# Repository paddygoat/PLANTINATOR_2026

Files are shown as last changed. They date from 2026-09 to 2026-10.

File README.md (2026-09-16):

# PLANTINATOR 2026

PLANTINATOR 2026 explores a practical way to develop machinery with complex moving geometry: describe the mechanism in Python, refine it with an LLM such as GPT Astra, and inspect its movement in a dedicated Qt5 simulation application. When the mechanism is ready for further engineering, construct the corresponding model in FreeCAD and add the surrounding structure. This combines repeatable geometry generation, rapid visual feedback, and conventional CAD detailing in one development workflow.

The real world objective is to build a transplanting machine simplified as below:
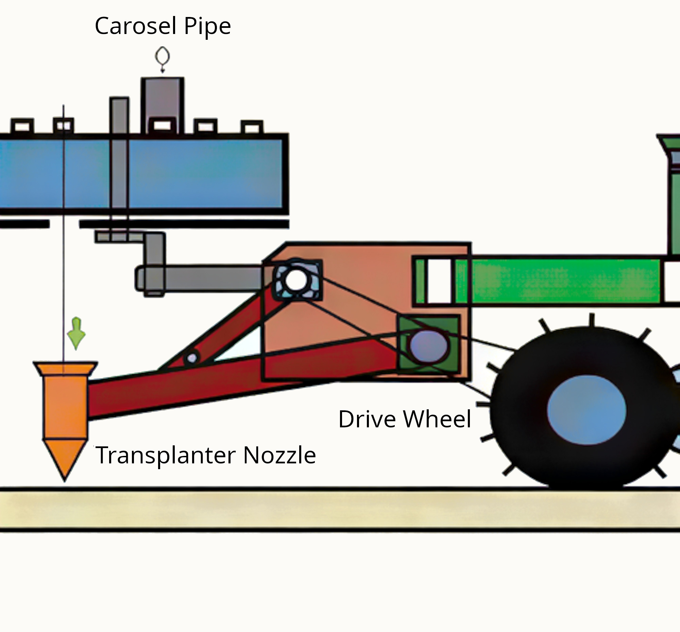
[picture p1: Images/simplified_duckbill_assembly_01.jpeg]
Simplified duckbill assembly


Progress so far:
Watch the PLANTINATOR video on YouTube (https://youtu.be/es3N6XBZsP0)

[Watch the video on YouTube](https://youtu.be/es3N6XBZsP0).

The repository contains a lugged wheel and chain mechanism, including paired wheels, a shared shaft, sprockets, and individual chain components. Its dimensions and motion relationships are expressed in code, making the assembly suitable for systematic changes rather than repeated manual reconstruction.

## Why describe moving geometry in Python?

Building an assembly manually in FreeCAD involves more than drawing its individual parts. Components must have consistent dimensions, occupy the correct positions, and maintain their intended relationships as the mechanism moves. Repeated features, such as wheel lugs and chain links, multiply the positioning work. A change to wheel spacing or sprocket geometry can affect several other parts of the design.

A Python macro captures these relationships explicitly. Dimensions become named parameters; repeated shapes come from functions and loops; placements follow mathematical rules. Instead of editing every affected component separately, the designer changes the relevant inputs and regenerates the assembly. FreeCAD also supports parametric modelling through its interface, but code makes large sets of repeated operations especially straightforward to reproduce and review.

In this project, parameters describe features such as disc diameter, lug count, chain pitch, and wheel spacing. The current sprocket tooth counts are 28, 15, and 21, despite older comments mentioning 13 teeth. Reading the executable parameters therefore matters more than relying on historical labels. The wheel and first sprocket share a defined rotational relationship, preserving their intended shaft synchronisation during animation.

## Working with an LLM

An LLM can help translate mechanical intentions into changes to the Python model. A request might be: “Increase the distance between the wheels while keeping the shaft ends flush with the outer bosses.” The useful result is a change to the relevant dimensions and relationships, which the designer can inspect, run, and revise.

This reduces the effort of writing repetitive modelling operations, tracing dependencies, and adjusting placement calculations. It also makes experimentation accessible through ordinary language. A designer can describe the desired arrangement, ask for an explanation of the geometry, and request a specific alteration without manually repeating every CAD operation.

The strongest workflow uses small, explicit requests. State the dimensions, coordinate directions, fixed relationships, and expected motion. Review the resulting code, then inspect the model. Keep successful revisions in version control so that alternatives can be compared or reversed. The LLM assists with implementation; the designer decides whether the mechanism meets its engineering requirements.

## Faster visual checks with Qt5

The dedicated application in [Simulator_app](Simulator_app/) shortens the feedback loop between changing a model and seeing it move. It uses PySide2 for Qt5, Pivy/Coin with OpenGL for display, and FreeCAD’s Part geometry kernel to construct the solids. It does not require the full FreeCAD desktop interface for each inspection.

That distinction is useful during frequent revisions. Opening FreeCAD, loading or rerunning a macro, waiting for document construction, and arranging the view introduces repeated interaction. The dedicated viewer concentrates on the mechanism and its controls, allowing human attention to stay on the geometry and motion. The practical speed advantage comes from this focused workflow and reuse of display geometry; no benchmark is claimed here.

The viewer displays tessellated CAD surfaces, including holes, chamfers, bosses, sprocket teeth, and chain details. During playback, it updates component transformations rather than rebuilding every solid for every frame. Controls include play/pause, signed speed, stepping by one chain pitch, and a position slider. Standard views, orbit, pan, zoom, lug inspection, and chain close-ups help examine details from useful angles.

Use **Load dimensions** to read supported numeric constants from a Python file and rebuild the view. This feature does not execute arbitrary selected macros: geometry comes from the bundled `source_model.py`. New geometry logic must therefore be incorporated into that source and the application restarted or rebuilt. Keep the CAD macro and simulator source consistent when developing changes.

Check the default source path before launching: the repository stores its CAD macro inside `CAD/`, while the simulator currently expects it at repository root.

## Continue the design in FreeCAD

The workflow retains a route into a native FreeCAD document. Open [FreeCAD_Simulator.FCMacro](Simulator_app/FreeCAD_Simulator.FCMacro) in FreeCAD and execute it, keeping its sibling files together. It runs the bundled geometry source and creates actual document objects. Save the resulting document as an `.FCStd` working file for subsequent editing.

This handoff is more precise than treating the standalone viewer as a general CAD exporter. The current application does not provide a universal working-file import/export pipeline. If dimensions were loaded from another file in the viewer, transfer those accepted values into the bundled source before generating the FreeCAD document. Verify that both environments show the same arrangement.

Once inside FreeCAD, static items can be added such as the supporting frame, bearing mounts, brackets, guards, or mounting plates. Use the mechanism’s shaft positions and movement envelope to guide their placement. Keep these additions organised separately and save a separate working document before rerunning generation code, which creates a fresh mechanism document. Generated solids do not automatically provide a complete sketch-based feature history.

## A practical development cycle

Start with the Python geometry, ask the LLM for a clearly bounded change, and inspect the revised mechanism in Qt5. Check several positions across a complete cycle, including close approaches and reversals. Once the arrangement is satisfactory, generate the FreeCAD document and develop the supporting structure around it.

The simulator uses a continuous pitch-circle approximation, rather than a rigid-link contact solver. It does not calculate loads, traction, tension, or collisions. Visual agreement supports geometric development, while fabrication still requires dimensional, clearance, and mechanical checks. Used together, Python, LLM assistance, Qt5 visualisation, and FreeCAD make complex mechanisms easier to iterate and understand.

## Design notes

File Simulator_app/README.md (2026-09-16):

# WEEDINATOR detailed wheel and chain simulator — v3.2

## Start the updated app

Close the older running app, then run:

```bash
python3 app.py
```

The window title reads **WEEDINATOR · detailed CAD viewer · Qt5 · v3.2**. This is now the default application. It uses installed **PySide2 (Qt5)**, **Pivy/Coin with OpenGL**, and **FreeCAD's Part geometry kernel**. These dependencies are present on the machine where the app was built. Use the system Python compatible with FreeCAD; installing a generic package named FreeCAD with pip is not a substitute. On a system with a different FreeCAD library location, set `FREECAD_LIB` to the directory containing `FreeCAD.so`. A desktop display and working OpenGL context are required.

## Front disc rendering update (v3.2)

CAD checks confirm that the disc is 590 mm in diameter, has a 6 mm axial thickness, two rearward chamfered steps and an intact 30 mm bore. The renderer now meshes each CAD face separately and supplies explicit analytic surface normals, keeping flat plate faces separate from rounded edges and bore walls. It also explicitly requests a 24-bit depth buffer, enables depth testing and writing, and tightens the camera clipping range around the assembly to improve separation of thin surfaces. These changes address rendering artifacts without changing dimensions.

Regression tests verify flat front/back normals, mesh bounds and volume, as well as the original lug details. The reported visual distortion cannot be directly confirmed in the build session because a desktop display is unavailable.

## OpenGL startup fix (v3.1)

The Linux launcher now selects Qt's X11/GLX desktop OpenGL backend to match the installed Coin library. QApplication is created before Coin initialisation. The viewer requests a compatibility context without requiring multisampling, makes its context current before drawing, and checks both Qt and native GLX before entering Coin's renderer. If context creation fails, the app pauses and shows an error instead of calling Coin without a context. It does not disable Coin's context assertion.

An X11/XWayland display is required. The launcher checks display connectivity before constructing QApplication. Settings are scoped to the app process; system graphics configuration is unchanged.

For a driver issue, try Mesa software rendering:

```bash
python3 app.py --software
```

This retains the detailed CAD solids and uses Mesa software OpenGL instead of hardware acceleration. It still requires a working graphical display.

## Why details were missing

The older Tkinter viewer manually drew simplified polygons. Its lug blades were plain rectangles; it never generated the hole cuts, chamfers or welded flange solids. Qt5 by itself cannot restore omitted geometry.

The new viewer builds the original bundled CAD geometry and tessellates its actual surfaces at a 0.15 mm tolerance for OpenGL display. This includes the **10 mm lug chamfers, 12 mm through-holes, 6 mm flanges, stepped wheel face, rim, boss, sprocket tooth cuts and chain plates/pins/rollers**. OpenGL depth testing handles visibility. The screen shows tessellated solids rather than the older schematic.

The lug holes run along the tangential direction through the blades, so the startup front view sees them edge-on. Click **Lug detail** to pause and focus on the first blade from a slightly oblique side angle. Chamfers and the through-hole can then be inspected. A hole can still be hidden by other geometry when viewing from a different direction.

The disc has two rearward 12 mm steps. Their 45-degree chamfers start at radii 200 mm and 105 mm, ending at 188 mm and 93 mm respectively. The central land is 24 mm behind the outer land, with the hub seated on it. The rear profile follows the stepped front at a 6 mm axial offset.

## Controls

The right-side **Simulation & 3D camera** panel includes:

- Play/Pause, step one pitch, reset motion, signed chain speed, and chain-position slider.
- Front, Back, Top, Right and Isometric views.
- Orbit horizontally/vertically, roll, pan and zoom.
- **Restore startup view**: restores the front orientation and full-assembly framing.
- **Lug detail**: pauses, shows the wheel and focuses on a blade.
- **Chain close-up**: frames the sprockets and chain.
- Wheel visibility and loading another file's numeric dimensions.

Drag to orbit. Shift-drag or right-drag to pan. Scroll to zoom. Camera changes do not alter mechanism dimensions or shaft synchronisation. Startup remains the previous front view; animation starts paused.

Startup defaults to `../lugged_wheel_with_sprockets_chain.py`, and the file picker starts at that file. The bundled lug geometry includes three 10 mm chamfers, including the inner corner furthest from the disc.

**Load dimensions** reads direct numeric constants from a macro with the same parameter names; missing values use bundled defaults. It does not execute the selected file. Only the trusted bundled `source_model.py` supplies executable geometry code. This is a simulator for this assembly family, not a general macro interpreter.

## Other entry points

The older lightweight Tkinter schematic remains available explicitly:

```bash
python3 app.py --schematic
```

It is simplified and does not display the new CAD details.

For a native FreeCAD document, open **FreeCAD_Simulator.FCMacro** inside FreeCAD and execute it. Keep all sibling files together. This version has its own Qt dock and retains the original axonometric startup view. It requires `FreeCADGui` and creates actual document objects; the standalone Qt5 app uses the geometry kernel without the FreeCAD desktop UI.

## Source fidelity and limits

The source has `T1 = 28` despite older comments saying 13T. The app uses **28T / 15T / 21T**, with 58 pitches at 12.7 mm: a 736.6 mm loop. The solved second centre is approximately (136.120482, 0) mm and the third is (0, −140) mm.

The wheel rotates 1:1 with the first sprocket, plus `WHEEL_PHASE_OFFSET`, at Z = −50 mm. Geometry is retained from the bundled source; the original user file is untouched.

Motion retains the original continuous pitch-circle approximation. Angular speed is chain speed divided by pitch radius, which differs slightly from ideal integer tooth ratios. Equal arc-distance roller spacing produces chords shorter than the fixed chain pitch on arcs, so slight link/roller alignment discrepancies can remain. This is not a rigid-link/contact solver and does not calculate loads, traction, tension or collisions.

## Verification

```bash
python3 -m unittest discover -s . -v
```

Fifteen tests cover OpenGL backend selection and the no-context render guard, as well as the original path/rotation behaviour, dimension input, schematic camera math, CAD lug validity, actual hole/chamfer cutouts, tessellated detail vertices and shaft synchronisation. CAD tests require FreeCAD's Python libraries.

The Qt5 window, CAD scene construction, playback operations and camera controls have also passed a headless smoke test with `QT_QPA_PLATFORM=offscreen`. A missing-context smoke test also confirms that rendering is skipped and an error is shown without a Coin abort. These checks do **not** validate the final OpenGL image: a working desktop display was unavailable in the build session.

## Plain boss and shaft

The plain front boss is OD 50 / ID 30 x 30 mm, seated on the recessed centre. A local-X diameter-12 hole passes through its midpoint with a simplified M12 x 70 hex bolt and nut (threads omitted). The OD 30 x 954 mm shared shaft extends rearward with its front (+Z) end flush with the boss front face and remains solid and undrilled. The bolt intentionally intersects the shaft pending a later shaft-hole change.

## Rear rim closure

The Ø550 mm rim extends 74 mm rearward from the main Ø590 mm disc. A Ø550 x 6 mm closing disc meets its far end and extends another 6 mm rearward (local Z −80 to −74 mm; total rearward depth 80 mm). Its Ø30 mm centre bore accommodates the shaft.

A second plain boss (OD 40 / ID 30 x 7 mm) is seated on the outside of the rear closing disc, extending rearward from local Z −80 to −87 mm.

## Second wheel

A complete second wheel, including both discs, rim, 12 lugs, both bosses and locking fasteners, is rotated 180 degrees about Y. The centres of the 80 mm rim + rear-disc envelopes are 850 mm apart along negative Z. Its reference plane is 930 mm behind the first. Both wheels rotate together with one solid OD 30 x 954 mm shaft, flush with the two outward-facing front boss faces. Shaft holes remain uncut.

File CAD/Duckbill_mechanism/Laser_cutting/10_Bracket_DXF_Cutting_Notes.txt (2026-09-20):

Units: millimetres. Scale 1:1. All geometry on CUT layer. No kerf compensation.
Horizontal bracket: cut 2 from 6 mm steel; 4 x diameter 10 holes at 15 mm pitch.
Upright bracket: cut 4 from 3 mm steel; 3 x diameter 6 holes, middle pivot offset outward 20 mm.
Rounded profiles and tube-fitting cutout are included.
[
  {
    "file": "10_Horizontal_Tube_Bracket_84x24_6mm_4Holes.dxf",
    "thickness_mm": 6,
    "quantity": 2,
    "width_mm": 84.0,
    "height_mm": 24.0,
    "closed_contours": 6,
    "entities": {
      "CIRCLE": 4,
      "LINE": 5,
      "ARC": 6
    }
  },
  {
    "file": "10_Upright_Bracket_OffsetPivot_3mm.dxf",
    "thickness_mm": 3,
    "quantity": 4,
    "width_mm": 42.0,
    "height_mm": 60.0,
    "closed_contours": 4,
    "entities": {
      "CIRCLE": 3,
      "LINE": 7,
      "ARC": 3
    }
  }
]

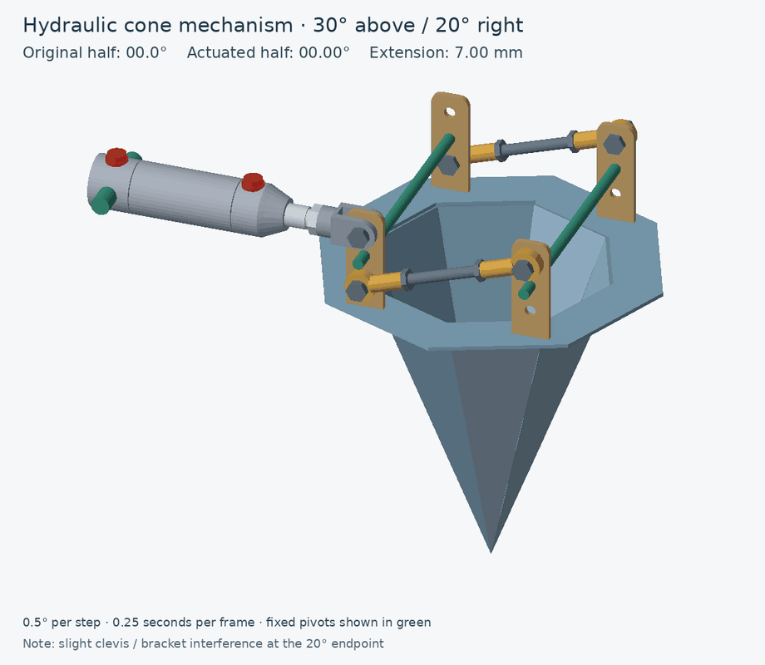
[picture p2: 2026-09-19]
Images/Hydraulic_Cone_3D_30Above_20Right_025sec.gif

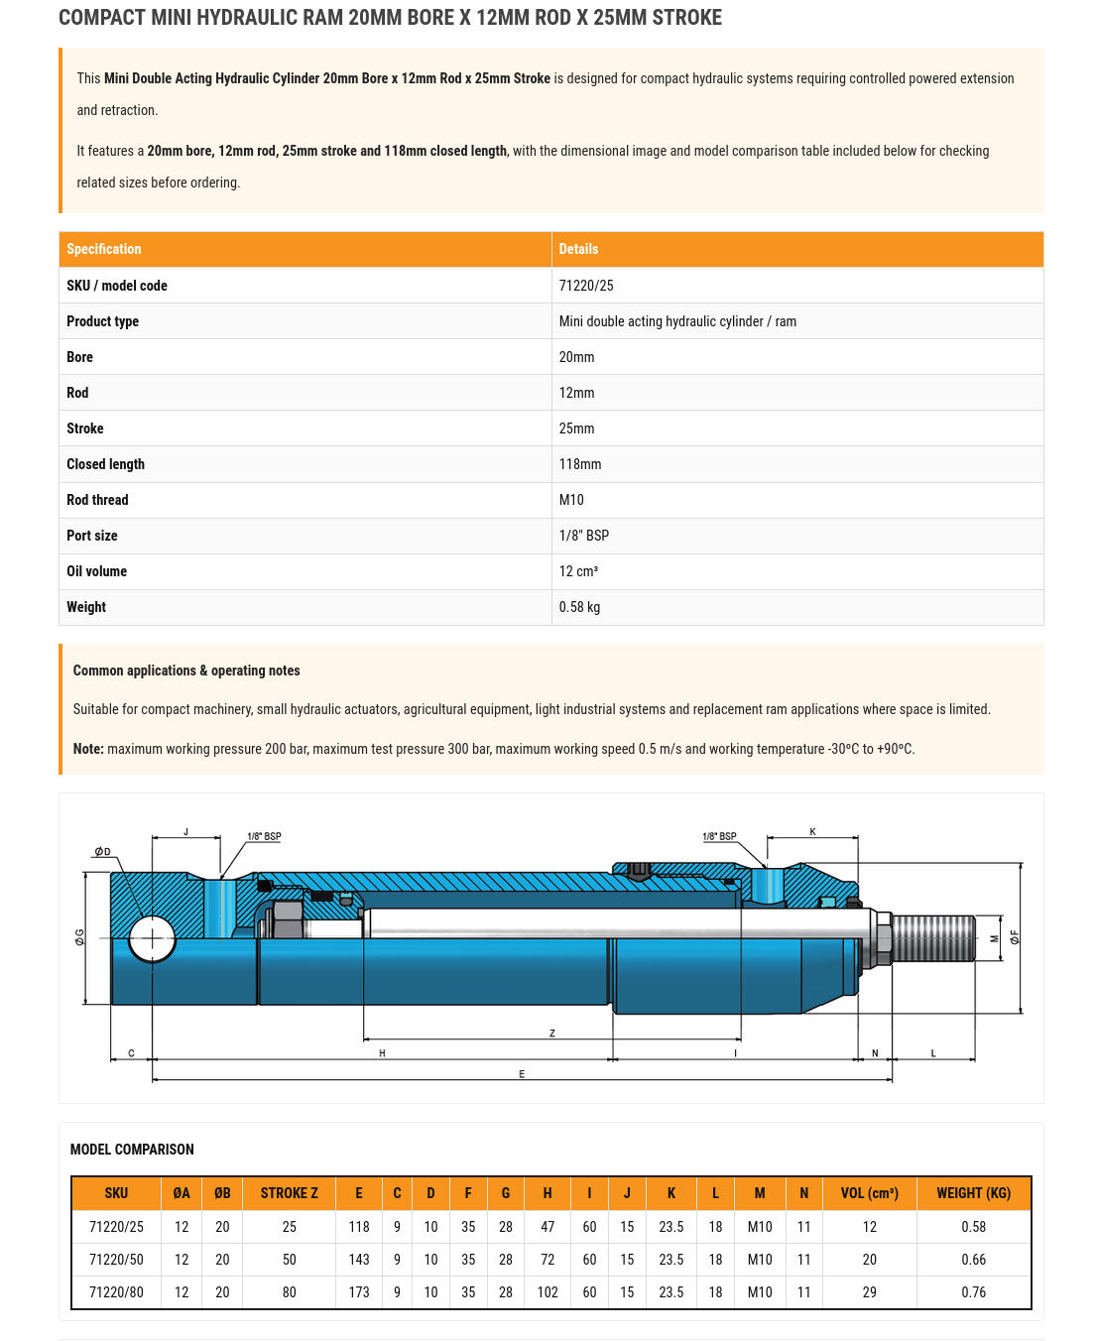
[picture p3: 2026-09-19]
Images/hydraulic_cylinder/Screenshot 2026-09-19 at 22-36-25 Mini Hydraulic Cylinder 20mm Bore x 25mm Stroke Flowfit.png

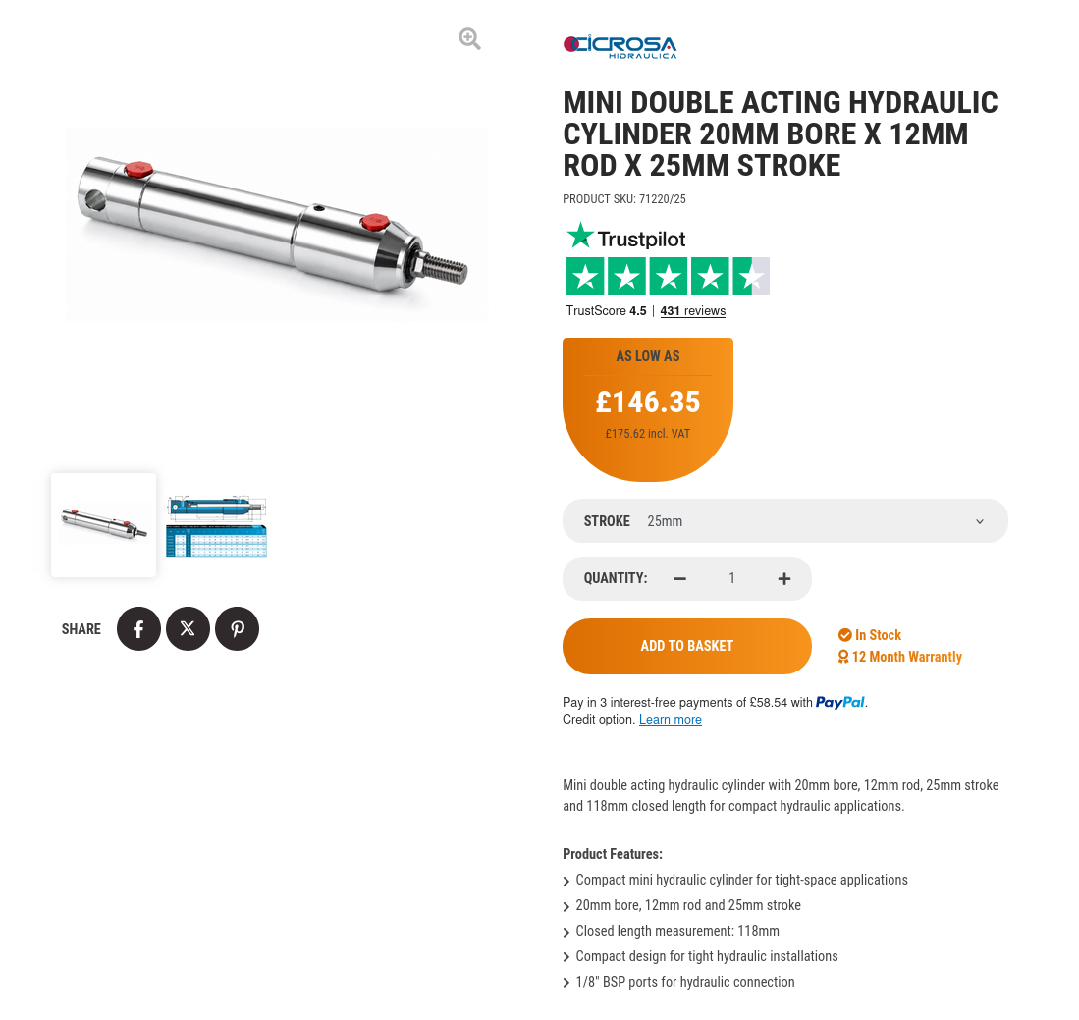
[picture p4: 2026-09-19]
Images/hydraulic_cylinder/Screenshot 2026-09-19 at 22-35-51 Mini Hydraulic Cylinder 20mm Bore x 25mm Stroke Flowfit.png

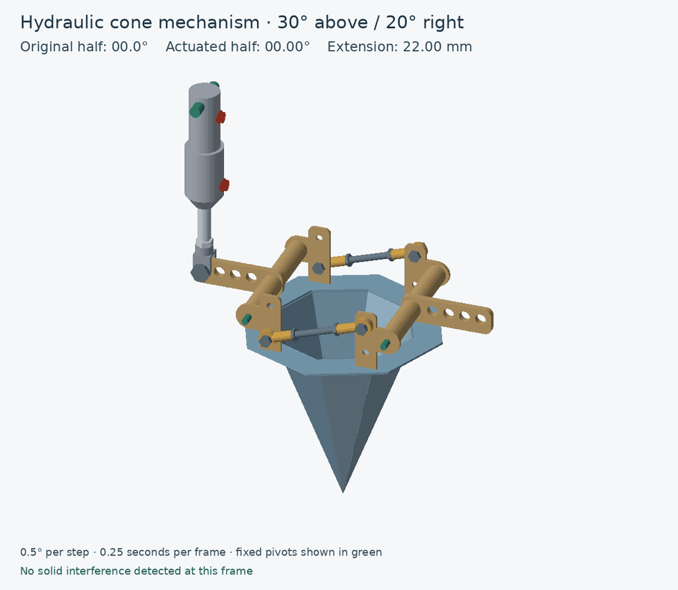
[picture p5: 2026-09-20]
CAD/Duckbill_mechanism/Images/10_Demi_Cone_Adjustable_Brackets_0_20_0.gif

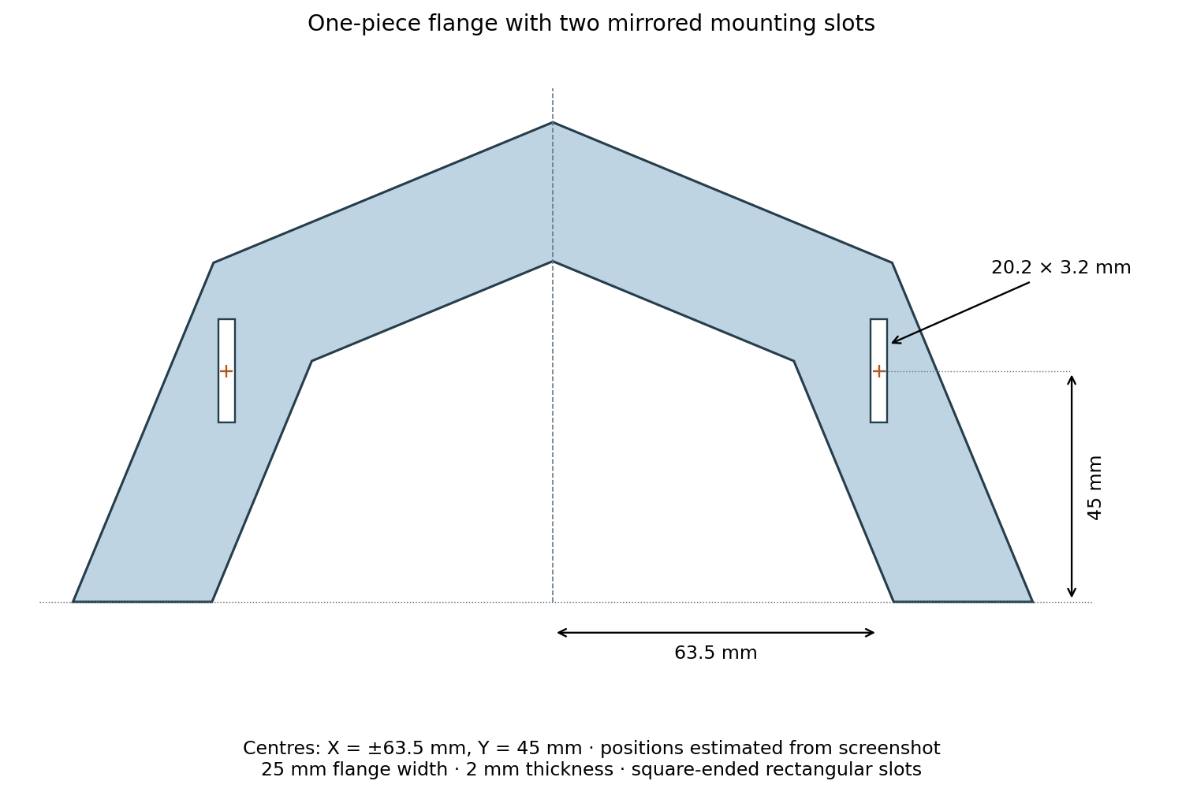
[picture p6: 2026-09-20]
CAD/Duckbill_mechanism/Laser_cutting/Flange_2Slots_Drawing.png

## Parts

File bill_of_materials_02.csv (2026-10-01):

Part Description | Num Reqd | Currency | Cost ex VAT each | Total cost incl VAT | Supplier 1 | Supplier 2 | Item Web Address
PrimaryChainDrive Orange 82L | 2 |  | n/a | n/a
Wheel shaft 64T to sprocket 10T_02 chain yellow 138L | 2 |  | n/a | n/a
Upper wheel 32T chain drive Green 60L | 2 |  | n/a | n/a
sprocket_16T_01 Orange 16T | 4 | £ | 7.85 | 9.42 | Simply Bearings |  | https://www.simplybearings.co.uk/products/pw-s-08b-16
sprocket 15T tensioners Orange Yellow 15T | 6 | £ | 7.63 | 9.16 | Simply Bearings |  | https://www.simplybearings.co.uk/products/pw-s-08b-15
wheel_shaft_sprocket_64T Yellow 64T 08B | 2 | £ | 35.11 | 84.264 | Simply Bearings |  | https://www.simplybearings.co.uk/products/pw-s-08b-64
sprocket_10T_02 Yellow 10T 08B | 2 | £ | 6.21 | 14.904 | Simply Bearings |  | https://www.simplybearings.co.uk/products/pw-s-08b-10
wheel shaft sprocket 32T 01 Green 32T 08B | 4 | £ | 14.95 | 71.76 | Simply Bearings |  | https://www.simplybearings.co.uk/products/pw-s-08b-32
upper wheel tensioner 12T 01 Green 12 T 08B | 2 | £ | 6.37 | 15.288 | Simply Bearings |  | https://www.simplybearings.co.uk/products/pw-s-08b-12
SKU: 08B-1-5MTR-MB Branded 08B-1 BS Simplex Roller Chain 1/2 inch Pitch 5 Meters, 394 L | 2 | £ | 27.2 | 65.28 | Simply Bearings |  | https://www.simplybearings.co.uk/products/08b-1-5mtr-mb
SRB45/2-20 15/30 Tooth Metric En8 Steel Bevel Gear Set 2:1 Ratio 4.5 MOD 20deg Pressure Angle | 1 | £ | 232.94 | 279.53 | Simply Bearings |  | https://www.simplybearings.co.uk/products/srb45-2-20-15-30-tran
SRB35/2 16/32 Tooth Metric En8 Steel Bevel Gear Set 2:1 Ratio 3.5 MOD 20deg Pressure Angle | 1 | £ | 146.59 | 175.91 | Simply Bearings |  | https://www.simplybearings.co.uk/products/srb35-2-16-32-tran
SRB30/2 16/32 Tooth Metric En8 Steel Bevel Gear Set 2:1 Ratio 3.0 MOD 20deg Pressure Angle | 1 | £ | 126.51 | 151.81 | Simply Bearings |  | https://www.simplybearings.co.uk/products/srb30-2-16-32-tran
Wilwood 0.750 inch Integral Brake/Clutch Master Cylinder – RD3621 260-1304 | 2 | £ | 42.43 |  | Rally Design |  | https://www.ebay.co.uk/itm/232571162100
Wilwood Pull Type Clutch Slave Master Cylinder – 260-1333 | 2 | £ | 86.99 |  | Rally Design |  | https://www.ebay.co.uk/itm/331572254785

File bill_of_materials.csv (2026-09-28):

Part DescriptionNum ReqdCurrencyCost ex VAT eachTotal cost incl VATSupplier 1Supplier 2Item Web Address
PrimaryChainDrive | Orange | 82L2n/an/a
Wheel shaft 64T to sprocket 10T_02 chain | yellow | 138L2n/an/a
Upper wheel 32T chain drive | Green | 60L2n/an/a
sprocket_16T_01 | Orange | 16T4
sprocket 15T tensioners | Orange | Yellow | 15T6
wheel_shaft_sprocket_64T | Yellow | 64T 08B2£35.1184.264Simply Bearingshttps://www.simplybearings.co.uk/products/pw-s-08b-64
sprocket_10T_02 | Yellow | 10T 08B2£6.2114.904Simply Bearingshttps://www.simplybearings.co.uk/products/pw-s-08b-10
wheel shaft sprocket 32T 01 | Green | 32T 08B4£14.9571.76Simply Bearingshttps://www.simplybearings.co.uk/products/pw-s-08b-32
upper wheel tensioner 12T 01 | Green | 12 T 08B2£6.3715.288Simply Bearingshttps://www.simplybearings.co.uk/products/pw-s-08b-12
SKU: 08B-1-5MTR-MB Branded 08B-1 BS Simplex Roller Chain 1/2 inch Pitch 5 Meters, 394 L2£27.265.28Simply Bearingshttps://www.simplybearings.co.uk/products/08b-1-5mtr-mb
Sub Total£251.496
Part DescriptionNum ReqdCurrencyCost ex VAT eachTotal cost incl VATSupplier 1Supplier 2Item Web Address

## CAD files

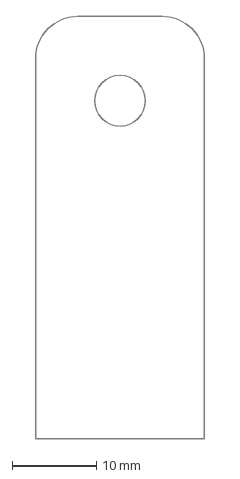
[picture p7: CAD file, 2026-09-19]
CAD/Duckbill_mechanism/Bracket_20x50x3_with_6mm_hole.dxf
20.0 x 50.0 mm

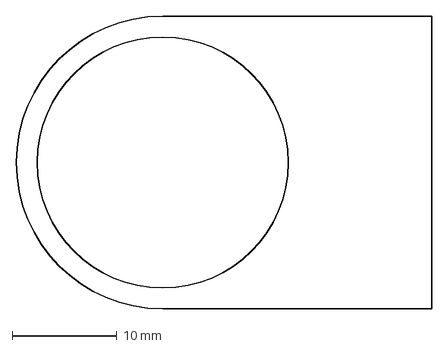
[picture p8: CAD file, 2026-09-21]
CAD/Duckbill_mechanism/Laser_cutting/Fixed_bracket_28mm_high_3mm_thick.dxf
39.7 x 28.0 mm

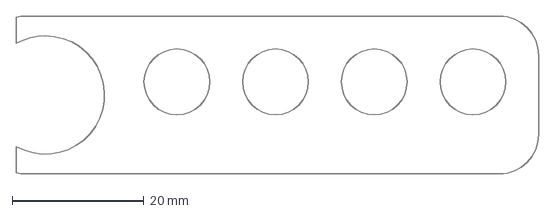
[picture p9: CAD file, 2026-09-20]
CAD/Duckbill_mechanism/Laser_cutting/16_Horizontal_Tube_Bracket_Trimmed_6mm_4Holes.dxf
79.4 x 24.0 mm

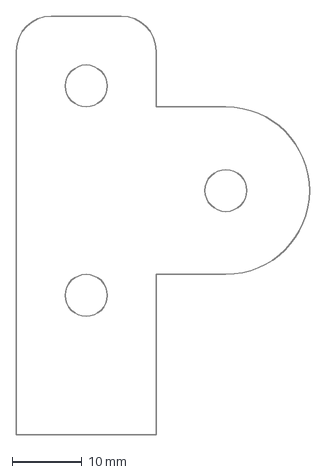
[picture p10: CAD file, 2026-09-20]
CAD/Duckbill_mechanism/Laser_cutting/10_Upright_Bracket_OffsetPivot_3mm.dxf
42.0 x 60.0 mm

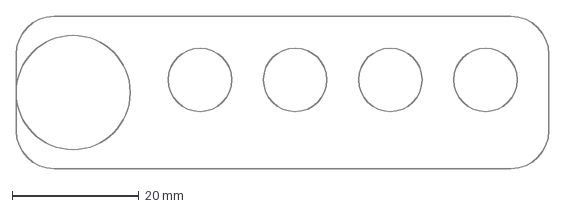
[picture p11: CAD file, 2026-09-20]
CAD/Duckbill_mechanism/Laser_cutting/10_Horizontal_Tube_Bracket_84x24_6mm_4Holes.dxf
84.0 x 24.0 mm

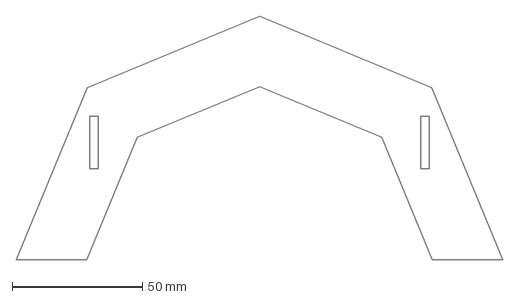
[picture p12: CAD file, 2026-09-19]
CAD/Duckbill_mechanism/Laser_cutting/DemiCone_Flange_2Slots_Flat.dxf
186.8 x 93.4 mm

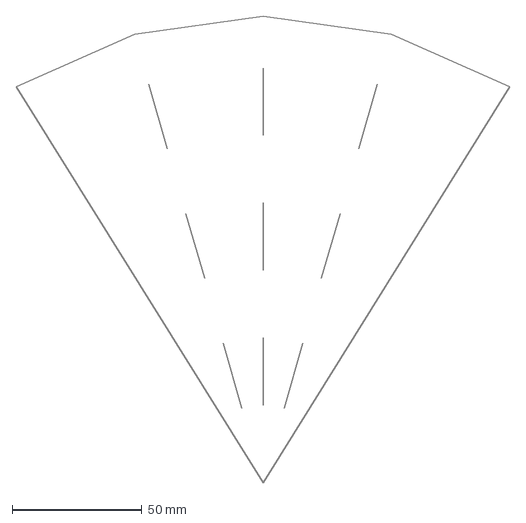
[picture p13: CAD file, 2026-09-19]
CAD/Duckbill_mechanism/Laser_cutting/DemiCone_Flat_SinglePass_01.dxf
190.4 x 180.0 mm
